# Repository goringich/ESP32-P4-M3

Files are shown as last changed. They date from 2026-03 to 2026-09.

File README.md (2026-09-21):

# ESP32-P4-M3 — spherical robot

This repository contains the ESP32-P4-M3 firmware/control stack and the current mechanical source for a pendulum-driven steerable spherical robot.

## Current engineering source of truth

The active mechanical project is:

`mechanical/spherical_robot/`

Key sources:

- `config/dimensions.json` — canonical mechanical dimensions, component envelopes and evidence status;
- `calculations.py` — deterministic sizing/load/traction screening;
- `blender/build_robot.py` + `blender/validate_robot.py` — exact assembly generation, topology and collision sweep;
- `simulation/` — reduced-order digital twin plus generated MuJoCo model contract;
- `DIGITAL_TWIN.md` — evidence ladder and commands;
- `NEEDS_MEASUREMENT.md` — physical measurements still required before final fits;
- `ASSEMBLY.md` and `PRINTING.md` — staged physical build path.

The historical `3D-model/fiish.*` files are not the current spherical-robot CAD authority.

## Verification

Dependency-free digital checks:

```bash
python -m unittest discover -s mechanical/spherical_robot/tests -p 'test_*.py'
python mechanical/spherical_robot/calculations.py --json
python mechanical/spherical_robot/simulation/run_sweep.py
python mechanical/spherical_robot/simulation/mujoco_model.py --output /tmp/spherical_robot.xml
```

Full geometry regeneration requires Blender:

```bash
blender --background --factory-startup --python mechanical/spherical_robot/blender/build_robot.py
```

MuJoCo, Project Chrono and FreeCAD/CalculiX are higher evidence layers. Their absence must be reported as pending/blocked; generated XML or Blender animation is not solver evidence and no simulation is physical validation.

## Firmware

ESP-IDF application code lives under `main/` and `components/`. The current repository includes MPU-9250, I2C, stepper/control, Wi-Fi/network and telemetry code.

Local/generated `sdkconfig` and `build/` remain ignored because they may contain machine-local configuration.

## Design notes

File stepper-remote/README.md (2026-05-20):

# Stepper Remote

This web stack is the operator UI for the ESP32-P4 gyroscope platform bench in this repo.

## What works

- Local web UI: served from the backend on `http://127.0.0.1:3001/`
- Serial workflow: browser -> local backend -> `/dev/ttyUSB0`
- Wi-Fi workflow: browser -> backend proxy -> ESP AP at `http://192.168.4.1`
- BLE status is exposed by firmware telemetry and shown in the UI

## One-command start

From the repo root:

```bash
./scripts/run_stepper_remote_web.sh
```

The script:

1. builds the frontend
2. builds the backend
3. starts the backend that serves the built frontend on `0.0.0.0:3001`

Then open:

- `http://127.0.0.1:3001/` for the main UI
- `http://127.0.0.1:3001/pad` for the simple pad view
- `http://<backend-host-ip>:3001/` from another device that can reach the backend host

## Important transport note

Opening the web UI locally and controlling the board over Wi-Fi are different things.

- The local UI can open as long as the backend is running.
- In `wifi` mode the browser talks only to the backend. The backend proxies requests to the ESP AP.
- Because of that, the browser device may stay on another Wi-Fi network if it can reach the backend host.
- But the backend host itself still must have a real route to the ESP AP: second adapter, dual-homed host, or router route.
- Wi-Fi transport from this PC to the ESP AP requires a real Wi-Fi adapter on the host.
- On this machine, recent checks showed `WIFI-HW missing`, so `http://192.168.4.1` is not reachable from this PC until Wi-Fi hardware is available.

Because of that:

- use `serial` mode from this workstation when working directly over USB
- use another phone/laptop with Wi-Fi if you want to drive the ESP AP over `wifi` mode
- or run the backend on a machine that can both reach `192.168.4.1` and expose `http://<backend-ip>:3001` to the browser device

## ESP AP credentials

- SSID prefix: `JC-ESP32P4M3`
- Password: `00000000`

## Backend ports

- backend API + static UI: `3001`
- frontend dev server, if you run it separately: Vite with `/api` proxy to `3001`

## Main API surfaces

- `GET /api/ports`
- `POST /api/connect`
- `POST /api/disconnect`
- `POST /api/command`
- `GET /api/telemetry`
- `GET /api/logs`
- `GET /api/logs/stream`
- `POST /api/transport`
- `POST /api/tooling/build`
- `POST /api/tooling/flash`

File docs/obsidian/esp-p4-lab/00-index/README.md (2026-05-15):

# ESP P4 Lab Documentation

Это корневая страница внутренней технической документации по проекту `p4_lab`.

Документация нужна не только чтобы "понять, где что лежит", а чтобы по ней можно было:

- быстро восстановить архитектуру проекта без чтения всего кода подряд;
- объяснить, как устроена прошивка, на защите или в курсовой;
- понять, какие подсистемы уже реализованы, а какие являются заготовками;
- брать готовые формулировки, схемы, цепочки вызовов и примеры кода.

## Что делает проект

Проект представляет собой прошивку для `ESP32-P4`, в которой объединены несколько учебно-практических задач:

- инициализация и диагностика `I2C`;
- обнаружение и опрос датчика семейства `MPU-9250`;
- управление шаговым двигателем через драйвер `L293D`;
- локальное управление через `UART`;
- сетевой доступ к состоянию и управлению через `Wi-Fi + HTTP + WebSocket`;
- периодическая выдача телеметрии в лог и в JSON.

По сути это лабораторный стенд, где одна прошивка показывает сразу несколько типовых подсистем встраиваемого ПО:

- low-level работа с шинами и GPIO;
- прикладной orchestration слой;
- сеть и API;
- телеметрия и диагностика;
- конфигурирование через `Kconfig`/`sdkconfig`.

## Краткая архитектура

Система разбита на понятные блоки:

- `main/main.c` — минимальная точка входа ESP-IDF;
- `components/app/src/app.c` — общий координатор жизненного цикла;
- `components/app/src/app_wifi.c` — запуск Wi‑Fi и хранение статуса;
- `components/app/src/app_net.c` — HTTP/WebSocket сервер и JSON API;
- `components/app/src/app_stepper.c` — логика шагового двигателя и команд;
- `components/app/src/app_mpu_pretty.c` — опрос MPU и форматирование телеметрии;
- `components/i2c_bus/src/i2c_bus.c` — универсальные операции I2C;
- `components/i2c_bus/src/i2c_bus_diag.c` — диагностика пар SDA/SCL;
- `components/mpu9250/src/mpu9250.c` — минимальный слой probe/WHO_AM_I.

Ключевая инженерная идея проекта: все внешние интерфейсы сводятся к небольшому набору публичных API, а `main` остается почти пустым.

## Что важно знать до чтения

1. Это не полный промышленный продукт, а учебно-исследовательская прошивка.
2. Некоторые функции есть как задел на будущее, но не везде уже встроены в активный runtime.
3. Документация ниже старается описывать именно **фактическое поведение текущего кода**, а не желаемое состояние.
4. Сеть сейчас строится вокруг SoftAP, а логика двигателя доступна и по UART, и через HTTP/WebSocket.

## Рекомендуемый маршрут чтения

Если нужно быстро войти в проект:

- [[00-index/Reading order]]
- [[02-architecture/System overview]]
- [[02-architecture/Boot and main loop]]
- [[02-architecture/Runtime data flow]]
- [[03-components/app component]]
- [[03-components/app_stepper]]
- [[03-components/app_net]]
- [[03-components/app_wifi]]
- [[03-components/i2c_bus]]
- [[03-components/mpu9250]]
- [[05-config/Configuration overview]]
- [[06-operations/Build and verification]]

Если нужен справочник:

- [[00-index/Function index]]
- [[00-index/Config index]]
- [[00-index/Source map]]

Если нужен материал именно под связный текст курсовой:

- [[08-course-paper/README]]
- [[08-course-paper/Technologies and stack]]
- [[08-course-paper/Engineering decisions]]
- [[08-course-paper/Current limitations]]
- [[08-course-paper/Future development]]

## Главные исходники

- `main/main.c`
- `components/app/src/app.c`
- `components/app/src/app_wifi.c`
- `components/app/src/app_net.c`
- `components/app/src/app_stepper.c`
- `components/app/src/app_mpu_pretty.c`
- `components/i2c_bus/src/i2c_bus.c`
- `components/i2c_bus/src/i2c_bus_diag.c`
- `components/mpu9250/src/mpu9250.c`
- `components/app/Kconfig`
- `components/i2c_bus/Kconfig`
- `sdkconfig`
- `sdkconfig.defaults`

## Что уже можно использовать в курсовой

Из этой базы уже можно брать:

- описание слоев архитектуры;
- последовательность загрузки и основного цикла;
- описание шины I2C и минимального драйверного слоя для MPU;
- описание сетевого API;
- описание схемы двойного управления двигателем;
- примеры структур состояния и JSON телеметрии;
- объяснение, как `Kconfig` влияет на состав функциональности.

Для более связного академического текста теперь также есть отдельный слой:

- стек технологий и платформы;
- инженерные решения по архитектуре;
- ограничения текущего прототипа;
- направления дальнейшего развития.

## Что сознательно не покрывается здесь

- `stepper-remote/backend`;
- `stepper-remote/frontend`;
- исходники внешнего SDK `esp-idf`;
- временные файлы сборки в `build/`.

Для них имеет смысл делать отдельный граф документации, чтобы не смешивать прикладную логику проекта с инфраструктурой SDK.

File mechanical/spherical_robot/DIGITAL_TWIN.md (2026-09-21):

# Spherical robot digital twin

## Goal

The digital twin binds the existing exact mechanical parameter/CAD pipeline to dynamics and later firmware/HIL evidence. It does **not** replace physical measurements or tests.

## Evidence ladder

1. `PARAMETER_CONTRACT_VALIDATED`
2. `ANALYTIC_BASELINE_PASS`
3. `CAD_COLLISION_SWEEP_PASS`
4. `PRIMARY_MULTIBODY_PASS` — MuJoCo execution
5. `INDEPENDENT_DYNAMICS_CROSSCHECK_PASS` — Project Chrono
6. `STRUCTURAL_ANALYSIS_PASS` — FreeCAD FEM/CalculiX when applicable
7. `CONTROLLER_IN_LOOP_PASS`
8. `HARDWARE_IN_LOOP_PASS`
9. `PHYSICAL_SUBASSEMBLY_PASS`
10. `PHYSICAL_SYSTEM_PASS`
11. `REPEATED_VALIDATION`

The repository deterministically produces levels 1–2, the existing Blender pipeline produces geometry/collision evidence for level 3, CI executes pinned MuJoCo 3.13.0 for level 4, and the dedicated heavyweight lane executes Project Chrono 10.0.0 as an independent level-5 cross-check. Levels 6+ remain separate evidence gates.

## Reduced-order model

`simulation/reduced_order.py` models one rolling plane using:

- sphere translation constrained to shell rotation;
- body translational + rotational inertia;
- absolute pendulum angle;
- equal/opposite motor torque between pendulum and body;
- gravity;
- damping/rolling-drag screening;
- motor torque-speed saturation;
- required floor contact force and normal-force estimate.

The model assumes no-slip rolling but computes a friction margin. Negative margin means that assumption is self-inconsistent and the scenario must be escalated to the contact solver; the code does not hide the violation by silently clamping it.

This model is deliberately not the authority for yaw/steering, contact compliance, shell deformation, backlash, battery sag, thermal behavior or real FDM material behavior.

## Reproducible baseline

```bash
python mechanical/spherical_robot/calculations.py --json
python -m unittest discover -s mechanical/spherical_robot/tests -p 'test_*.py'
python mechanical/spherical_robot/simulation/run_sweep.py
```

The sweep varies the existing ballast masses, arm radii and configured friction assumptions. Its output is provisional while the repository still contains `PLACEHOLDER`/`ASSUMED` inputs.

## MuJoCo

Generate an MJCF input artifact directly from canonical dimensions:

```bash
python mechanical/spherical_robot/simulation/mujoco_model.py \
  --output /tmp/spherical_robot.xml
```

XML generation alone remains `GENERATED_MODEL_NOT_EXECUTED`. The separate
`simulation/run_mujoco.py` path installs/executes pinned MuJoCo 3.13.0 in CI,
runs all 27 ballast/arm/friction combinations, verifies stable shell-floor
contact, bounded penetration, finite state, torque-speed limiting and a
positive/negative torque symmetry check, and records exact source hashes plus
solver/runtime versions. Only that executed path may emit
`PRIMARY_MULTIBODY_PASS`.

Run it locally after installing the pinned dependency:

```bash
python -m pip install -r mechanical/spherical_robot/simulation/requirements-simulation.txt
MUJOCO_GL=egl python mechanical/spherical_robot/simulation/run_mujoco.py
```

A MuJoCo pass still leaves the design verdict `PROVISIONAL` while canonical
inputs remain `PLACEHOLDER`/`ASSUMED`; it does not imply physical acceptance.

The MuJoCo model contains:

- free spherical body/contact shell;
- internal steering-yaw joint;
- pendulum hinge and ballast;
- bounded motor actuators;
- floor contact/friction;
- IMU-like accelerometer/gyro plus joint sensors.

## Independent cross-check and FEA

Release-critical dynamics must be cross-checked with Project Chrono (or another independently implemented multibody method). Load-bearing geometry requiring more than analytical screening must use FreeCAD FEM/CalculiX or a justified equivalent, with loads bound to the dynamics evidence.

## Controller and HIL

The next software layer should expose a stable semantic interface:

- IMU acceleration/angular velocity;
- pendulum angle/speed;
- steering angle;
- requested pendulum torque/speed;
- requested steering actuation;
- health/saturation/watchdog state.

The real control algorithm should first run controller-in-loop against the simulated plant. After that, the ESP32-P4-M3 can run HIL against the same interface. HIL still does not prove real floor friction, printed fit, RF, battery, thermal or wear behavior.

## Physical calibration loop

After the first safe subassembly/rolling tests, feed measured values back into the model:

- actual total/component masses and COM;
- actual motor torque-speed-current behavior;
- backlash/deadband;
- floor/grip friction;
- rolling resistance;
- IMU bias/noise/latency;
- battery sag;
- real pendulum and steering limits.

Every calibration update invalidates dependent simulation evidence until rerun.

## Project Chrono independent cross-check

The heavyweight CI lane uses official PyChrono 10.0.0 through its recommended
Conda distribution. `simulation/run_chrono.py` rebuilds an independent
Y-up/NSC/Bullet rigid-body model rather than reusing MuJoCo internals. It runs
the same 27 ballast/arm/friction scenarios and a ±torque symmetry pair.

`simulation/compare_multibody.py` then binds both solver reports to the same
canonical source hashes and checks scenario identity, rolling direction
agreement, bounded median response magnitude and independent symmetry. This may
emit `INDEPENDENT_DYNAMICS_CROSSCHECK_PASS`; it still cannot set
`physical_accepted=true`.

## Structural FEA screening

`fea/run_structural_fea.py` runs the tracked `PENDULUM_ARM.stl` through
Gmsh and CalculiX. Until coupon-backed anisotropic FDM properties and the final
slicer topology are bound, a green solve is only
`STRUCTURAL_FEA_SCREENING_PASS`, not `STRUCTURAL_ANALYSIS_PASS` and never
physical acceptance. See `STRUCTURAL_FEA.md`.

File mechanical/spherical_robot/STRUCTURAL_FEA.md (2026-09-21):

# Structural FEA screening

This lane adds a real finite-element solver check for the most load-sensitive
printed pendulum member: `PENDULUM_ARM.stl`.

## Evidence level

A successful run emits:

`STRUCTURAL_FEA_SCREENING_PASS`

It deliberately does **not** emit `STRUCTURAL_ANALYSIS_PASS`.

The tracked STL is meshed and solved, but printed PETG is currently represented
as an assumed isotropic solid. The real part uses walls + infill and has
direction-dependent FDM properties. Coupon-backed properties and a release load
case are required before structural release authority.

## Pipeline

```
tracked PENDULUM_ARM.stl
  -> Gmsh 4.15.2 surface classification
  -> first-order tetrahedral volume mesh
  -> CalculiX C3D4 static solve
  -> integration-point stress
  -> nodal displacement
  -> fail-closed screening report
```

The solver uses N/mm/MPa units.

## Load case

The screening load uses the maximum configured ballast mass plus the current
assumed pendulum-extra mass, multiplies it by a 5 g shock factor, and assigns
half to one arm. The root end is fixed and the force is distributed over the
opposite end in the weakest bending direction.

This is intentionally conservative, but it is still an abstraction of the real
two-bolt hub and ballast-saddle interfaces.

## Local run

Ubuntu/Debian dependencies:

```bash
sudo apt-get install calculix-ccx libglu1-mesa
python -m pip install -r mechanical/spherical_robot/fea/requirements-fea.txt
python mechanical/spherical_robot/fea/run_structural_fea.py
```

The report always retains `physical_accepted=false`.

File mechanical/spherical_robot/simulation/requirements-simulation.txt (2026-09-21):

# Primary multibody solver used by the spherical-robot exact-head CI.
# Pin the engine version so evidence can be tied to one deterministic solver release.
mujoco==3.13.0

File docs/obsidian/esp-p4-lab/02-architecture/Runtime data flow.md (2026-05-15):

# Runtime data flow

Этот раздел описывает, как реальные данные и команды проходят через систему во время выполнения.

## 1. Поток запуска системы

После загрузки микроконтроллера выполняется следующий сценарий:

1. `app_main()` пишет лог `boot`.
2. `app_main()` вызывает `app_init()`.
3. `app_init()` по очереди поднимает:
	- I2C;
	- I2C scan;
	- MPU WHO_AM_I check;
	- Wi‑Fi smoke run, если включен;
	- stepper subsystem, если включен режим `L293D_TEST`;
	- HTTP/WebSocket API, если включена сеть и Wi‑Fi успешно поднят.
4. Затем `app_main()` переходит в бесконечный цикл `app_tick()`.

Идея в том, что тяжелая инициализация выполняется один раз, а дальше система живет за счет коротких периодических вызовов.

## 2. Поток управления шаговым двигателем

### Через UART

Путь данных:

`UART0` → `app_stepper_handle_uart()` → `app_stepper_handle_command()` → изменение `s_stepper`

Подробно:

- `app_stepper_tick()` опрашивает UART, если `uart_ready == true`;
- считанные байты перебираются по одному;
- каждый символ интерпретируется как команда (`f`, `r`, `s`, `w`, `+`, `-`, и т.д.);
- обработчик обновляет внутренний state machine двигателя.

### Через HTTP

Путь данных:

HTTP `POST /api/command` → `app_net_command_handler()` → `app_net_extract_command()` → `app_stepper_command_char()` → `app_stepper_handle_command()`

Сетевой слой не знает, как именно устроены фазы двигателя. Он только выделяет символ команды и передает его вниз.

### Через WebSocket

Путь данных:

WebSocket text frame → `app_net_ws_handler()` → `app_net_extract_command()` → `app_stepper_command_char()` → `app_stepper_handle_command()`

Это тот же самый исполнительный путь, что и в HTTP. Разница только в транспорте.

## 3. Поток вычисления шага двигателя

Даже если новых команд нет, `app_stepper_tick()` продолжает обслуживать state machine.

### В режиме `sweep`

Алгоритм такой:

- двигатель идет вперед до `APP_STEPPER_SWEEP_STEPS`;
- затем делается пауза `APP_STEPPER_EDGE_PAUSE_MS`;
- после этого двигатель идет назад;
- потом снова пауза;
- цикл повторяется.

Внутри этого механизма используются:

- `s_stepper.mode`;
- `s_stepper.sweep_state`;
- `s_stepper.last_step_ms`;
- `s_stepper.pause_started_ms`;
- `s_stepper.moved_steps_in_leg`.

Физическое движение реализуется через последовательное включение фаз из массива `s_phases`.

## 4. Поток получения телеметрии MPU

Путь данных:

`app_tick()` → `app_mpu_pretty_log_line()` → `app_mpu_pretty_init()` → `i2c_bus_read()` → вычисление физических значений → лог + status + telemetry line

Что происходит по шагам:

1. Раз в секунду `app.c` решает, что пора вывести телеметрию.
2. Если MPU еще не инициализирован, вызывается `app_mpu_pretty_init()`.
3. Через `mpu9250_probe_and_read_whoami()` определяется адрес и код `WHO_AM_I`.
4. Через `i2c_bus_read()` читаются `GYRO_CONFIG`, `ACCEL_CONFIG`, а затем блок данных с `ACCEL_XOUT_H`.
5. Сырые 16-битные значения переводятся в:
	- ускорения в `g`;
	- угловые скорости в `dps`;
	- температуру в `°C`.
6. Результат одновременно:
	- печатается в красивом текстовом виде;
	- сохраняется в `app_mpu_status_t`;
	- публикуется как строка `@telemetry {...}`.

## 5. Поток системной телеметрии

Раз в секунду `app.c` также обновляет общий статус системы:

- `ready`;
- `uptime_ms`;
- `tick`;
- `tick_delay_ms`;
- `firmware`;
- `app_mode`;
- `last_error`.

Затем печатается отдельная telemetry-строка вида:

```text
@telemetry {"kind":"system", ...}
```

Это важно, потому что системная телеметрия и сенсорная телеметрия формируются независимо, но на одинаковой идее — выдавать машинно-читаемый JSON в лог.

## 6. Поток сборки JSON для сети

Путь данных:

`app_net_build_json()` ← `app_stepper_get_snapshot()`
`app_net_build_json()` ← `app_wifi_get_status()`
`app_net_build_json()` ← `app_get_system_status()`
`app_net_build_json()` ← `app_mpu_get_status()`
`app_net_build_json()` ← `app_get_i2c_status()`

Это один из самых важных архитектурных моментов.

`app_net` ничего не "вытаскивает" из чужих внутренних static-переменных. Он получает готовые слепки состояния через публичный API. В результате:

- связи между компонентами слабее;
- сетевой слой проще менять;
- состояние удобно сериализовать;
- документация на API становится понятнее.

## 7. Поток отдачи данных наружу

### HTTP pull-модель

- `GET /api/telemetry` → возвращает полный JSON состояния;
- `GET /api/wifi` → возвращает Wi‑Fi статус.

### WebSocket push-модель

Раз в секунду `app_net_tick()`:

- получает список клиентских сокетов;
- проверяет, какие из них являются WebSocket-клиентами;
- собирает единый JSON;
- ставит асинхронную отправку через `httpd_queue_work()`.

Эта схема удобна для web-dashboard: клиент не обязан постоянно опрашивать REST endpoint.

## 8. Поток ошибок и деградации

В проекте предусмотрена мягкая деградация, а не только "успех или аварийный стоп".

Примеры:

- если I2C init не удался, `app_init()` пишет ошибку и прекращает дальнейшую инициализацию;
- если MPU не найден, выполняется дополнительная диагностика пар GPIO;
- если Wi‑Fi поднять не удалось, сетевой API не стартует;
- если UART driver не поднялся, логика двигателя все равно остается доступной внутри прошивки и через сетевой слой;
- ошибки MPU записываются в `last_error` и публикуются в телеметрии.

## 9. Главная архитектурная развязка

В текущем проекте особенно важно следующее разделение:

- `app_net` не знает внутренних enum и state machine двигателя;
- `app_net` не трогает GPIO напрямую;
- `app_wifi` не знает про шаговый двигатель;
- `app_stepper` не знает ничего про HTTP server и WebSocket;
- `app_mpu_pretty` не знает ничего про HTTP, но публикует состояние, которое сеть потом читает;
- `app.c` выступает единственным orchestration-слоем.

Именно это делает проект пригодным для масштабирования и хорошим примером для пояснения в курсовой работе.

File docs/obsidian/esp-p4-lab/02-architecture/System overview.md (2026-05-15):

# System overview

## Назначение системы

Прошивка `p4_lab` — это учебно-прикладная embedded-система для `ESP32-P4`, в которой одновременно демонстрируются несколько важных подсистем:

- циклическая архитектура приложения поверх `FreeRTOS`;
- конфигурируемая работа с `I2C`;
- обнаружение и опрос `MPU-9250`;
- управление шаговым двигателем через `L293D`;
- локальное управление через `UART`;
- удаленное управление и чтение телеметрии через `Wi‑Fi`, `HTTP` и `WebSocket`.

Проект хорошо подходит как основа для курсовой, потому что в нем есть и работа с железом, и сетевой API, и конфигурируемая архитектура, и телеметрия.

## Слои архитектуры

Прошивка разделена на несколько уровней ответственности.

### 1. Входной слой

- `main/main.c`

Этот слой намеренно минимален. Он не знает деталей ни про Wi‑Fi, ни про I2C, ни про шаговый двигатель. Его задача — запустить прикладной слой и поддерживать бесконечный цикл:

- `app_init()` один раз;
- `app_tick()` в цикле;
- задержка между итерациями через `app_tick_delay_ms()`.

### 2. Прикладной координационный слой

- `components/app/src/app.c`

Здесь собрана общая логика жизненного цикла. Файл:

- инициализирует подсистемы в нужном порядке;
- хранит системный статус;
- хранит сводный статус I2C/MPU обнаружения;
- решает, запускать ли сетевой API;
- раз в секунду порождает телеметрию.

Это фактический центр композиции всего проекта.

### 3. Инфраструктурные и прикладные модули

- `app_wifi` — сеть;
- `app_net` — API и транспорт JSON/WS;
- `app_stepper` — исполнительный механизм;
- `app_mpu_pretty` — сенсорная телеметрия;
- `i2c_bus` — базовая шина;
- `mpu9250` — минимальный sensor helper.

## Схема связей между модулями

В текущей реализации зависимости выглядят так:

- `main` зависит только от `app`;
- `app` зависит от `app_wifi`, `app_net`, `app_stepper`, `app_mpu_pretty`, `i2c_bus`, `mpu9250`;
- `app_net` зависит от публичных snapshot/status API других подсистем;
- `app_mpu_pretty` зависит от `i2c_bus` и `mpu9250`;
- `mpu9250` зависит от `i2c_bus`.

Важно, что сетевой слой **не управляет GPIO напрямую** и **не работает с внутренними enum stepper напрямую**. Он общается с моторной подсистемой через маленький публичный API:

- `app_stepper_command_char()`;
- `app_stepper_get_snapshot()`.

Это хорошее архитектурное решение: транспорт и исполнительная логика разделены.

## Ключевая идея проекта

Главная идея системы — объединить несколько каналов управления и наблюдения, но не перемешивать их реализацию.

### Единый обработчик команд

Локальный `UART` и сетевые команды работают через один и тот же обработчик моторных команд. Это дает:

- одинаковое поведение независимо от канала управления;
- меньше дублирования логики;
- более простую отладку;
- единый формат состояния двигателя.

### Телеметрия как отдельный слой

Проект не ограничивается "сделать действие". Он еще и показывает состояние:

- через текстовый лог в UART/monitor;
- через JSON по `HTTP`;
- через push-модель по `WebSocket`;
- через отдельные `@telemetry` строки, пригодные для дальнейшего парсинга.

Это особенно полезно для стенда, лабораторной работы и курсовой, потому что можно показать не только код, но и наблюдаемое поведение системы.

## Что именно уже реализовано в текущем коде

### Реализовано точно

- инициализация I2C-шины;
- быстрый scan MPU-адресов `0x68` и `0x69`;
- fallback-диагностика альтернативных пар SDA/SCL при неудаче;
- чтение `WHO_AM_I`;
- чтение сырых значений accel/gyro/temp;
- вычисление физических величин;
- автоматический запуск stepper в режиме `sweep`;
- прием команд через `UART0`;
- REST endpoint для телеметрии;
- REST endpoint для Wi‑Fi статуса;
- REST endpoint для команд stepper;
- WebSocket endpoint;
- периодическая рассылка JSON по WebSocket.

### Есть в коде, но не полностью задействовано

- функция `app_wifi_log_scan_results()` существует, но в текущем коде не вызывается;
- функция построения SSID умеет добавлять MAC-суффикс, но сейчас вызывается с `NULL`, поэтому реально используется только `CONFIG_APP_WIFI_AP_SSID_PREFIX` без суффикса;
- выбор режима приложения через `choice APP_MODE` существует в `Kconfig`, но `app.c` фактически использует `CONFIG_APP_MODE_L293D_TEST` и логику MPU параллельно, то есть проект уже не является строго "однорежимным" в архитектурном смысле.

Эти детали важно зафиксировать в документации, потому что для курсовой полезно показывать не только сильные стороны, но и реальные инженерные компромиссы.

## Сильные стороны архитектуры

- маленький и чистый `main`;
- четкое разделение по компонентам;
- конфигурируемость через `Kconfig`;
- единая точка orchestration в `app.c`;
- общий обработчик команд stepper для разных транспортов;
- отдельный status/snapshot API для интеграции с сетью;
- упор на диагностику и наблюдаемость.

## Ограничения текущего варианта

- нет отдельной RTOS-задачи на каждую подсистему — используется один кооперативный tick-loop;
- JSON собирается вручную через `snprintf`, без полноценной JSON-библиотеки;
- `i2c_bus_read()`/`write()` каждый раз создают и удаляют device handle, что просто, но не оптимально для высокой частоты опроса;
- Web UI живет вне этой части документации;
- проект больше ориентирован на лабораторный стенд, чем на production deployment.

## Почему такая архитектура удобна для курсовой

Она дает материал сразу по нескольким темам:

- архитектура embedded-приложения;
- модульность и слои ответственности;
- работа с периферией и датчиками;
- управление исполнительным устройством;
- взаимодействие микроконтроллера и сети;
- телеметрия и диагностика;
- конфигурирование и сборка в ESP-IDF.

См. также:

- [[02-architecture/Boot and main loop]]
- [[02-architecture/Runtime data flow]]
- [[02-architecture/UART and network dual control]]
- [[02-architecture/WiFi HTTP WebSocket architecture]]

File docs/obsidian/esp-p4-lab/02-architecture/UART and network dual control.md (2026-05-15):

# UART and network dual control

## Архитектурная задача

Одна из главных задач проекта — расширить управление шаговым двигателем через сеть, но не потерять уже существующее UART-управление.

Это важный инженерный сценарий: часто в embedded-проектах новый интерфейс нужно добавить поверх старого, не ломая уже работающий способ диагностики и ручного контроля.

## Принцип решения

В проекте выбрано очень удачное решение:

- UART остается внутри `app_stepper.c`;
- сетевой слой не дублирует motor logic;
- наружу добавляется компактный публичный вызов `app_stepper_command_char(char cmd)`;
- и UART, и сеть в итоге сходятся в одном внутреннем обработчике `app_stepper_handle_command(uint8_t cmd)`.

Это означает, что логика интерпретации команд реализована **один раз**.

## Потоки управления

### Путь UART

```text
UART0 -> app_stepper_handle_uart -> app_stepper_handle_command
```

### Путь HTTP

```text
POST /api/command -> app_net_command_handler -> app_stepper_command_char -> app_stepper_handle_command
```

### Путь WebSocket

```text
/ws text frame -> app_net_ws_handler -> app_stepper_command_char -> app_stepper_handle_command
```

Таким образом, три разных транспортных входа приводят к одной и той же исполнительной логике.

## Почему это важно

Такой подход дает сразу несколько преимуществ:

- нет копипасты командной логики;
- поведение одинаково независимо от источника команды;
- проще тестировать и отлаживать;
- при добавлении новой команды ее нужно реализовать в одном месте;
- старый UART-канал продолжает работать как fallback и инструмент отладки.

## Набор команд остается единым

Сохраняется совместимость команд:

- `f`, `r`, `s`, `w`
- `1`, `2`
- `a`, `b`, `c`, `d`
- `+`, `-`
- `z`

То есть оператор, который привык управлять двигателем через UART-символы, фактически может использовать тот же протокол через HTTP/WebSocket.

## Почему это хорошее решение для курсовой

На этом месте можно показать важный инженерный принцип:

> новые интерфейсы не должны дублировать бизнес-логику, они должны переиспользовать существующий domain layer.

В терминах архитектуры проекта:

- `UART` и `HTTP/WebSocket` — это transport layer;
- `app_stepper_handle_command()` — это command execution layer.

## Ограничения текущей схемы

- команды односимвольные, поэтому протокол простой, но не слишком расширяемый;
- нет механизма очередей команд или приоритетов между каналами;
- нет явной арбитрации, если UART и сеть начнут слать команды очень часто одновременно;
- вся обработка выполняется внутри общего tick-loop.

Однако для лабораторного стенда такая схема оптимальна: она проста, надежна и очень понятна при объяснении.

## Практический смысл

В реальной демонстрации это дает очень удобный набор возможностей:

- можно управлять мотором с serial monitor;
- можно управлять через `curl`;
- можно подключить web-клиент;
- при проблемах с сетью UART остается резервным способом контроля.

Именно это делает проект не просто набором отдельных функций, а удобной экспериментальной платформой.

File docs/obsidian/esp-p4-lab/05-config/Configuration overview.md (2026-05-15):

# Configuration overview

## Зачем здесь нужен отдельный раздел про конфигурацию

В ESP-IDF проекте значительная часть поведения определяется не только кодом, но и конфигурацией. В `p4_lab` это особенно заметно: через конфиг управляются:

- состав активных подсистем;
- GPIO для I2C и stepper;
- частота I2C;
- параметры Wi‑Fi;
- включение сетевого API;
- параметры UART и LED для stepper.

То есть для полного понимания проекта нужно читать и код, и конфигурацию вместе.

## Главные файлы конфигурации

- `components/app/Kconfig`
- `components/i2c_bus/Kconfig`
- `sdkconfig`
- `sdkconfig.defaults`
- `CMakeLists.txt`

## Роль каждого файла

### `components/app/Kconfig`

Описывает прикладные настройки проекта:

- режим приложения;
- включение tick-логирования;
- Wi‑Fi smoke run;
- параметры SoftAP;
- включение попытки STA-подключения;
- включение HTTP/WebSocket API;
- GPIO и timing для L293D;
- настройки UART stepper;
- optional LED activity.

### `components/i2c_bus/Kconfig`

Описывает инфраструктурные параметры I2C:

- `CONFIG_I2C_BUS_SDA_GPIO`;
- `CONFIG_I2C_BUS_SCL_GPIO`;
- `CONFIG_I2C_BUS_FREQ_HZ`.

### `sdkconfig`

Это итоговая конфигурация текущей сборки. Именно она реально влияет на компиляцию и работу прошивки в данной рабочей копии.

### `sdkconfig.defaults`

Хранит базовые значения по умолчанию, которые особенно важны при создании новой конфигурации или переносе проекта на другое рабочее место.

## Важные настройки `components/app/Kconfig`

### Выбор режима приложения

В `Kconfig` есть выбор:

- `APP_MODE_MPU9250`
- `APP_MODE_L293D_TEST`

Но важно понимать практический нюанс: текущий код уже использует и моторную, и MPU-логику одновременно. Поэтому формально `choice` есть, но архитектурно проект уже вышел за рамки строго одного режима.

### Логирование

- `CONFIG_APP_TICK_LOG`

Когда включено, `app.c` раз в секунду генерирует системную и MPU-телеметрию.

### Wi‑Fi

- `CONFIG_APP_WIFI_SMOKE`
- `CONFIG_APP_WIFI_AP_SSID_PREFIX`
- `CONFIG_APP_WIFI_AP_PASSWORD`
- `CONFIG_APP_WIFI_AP_CHANNEL`
- `CONFIG_APP_WIFI_SCAN_MAX_AP`
- `CONFIG_APP_WIFI_CONNECT`
- `CONFIG_APP_WIFI_SSID`
- `CONFIG_APP_WIFI_PASSWORD`
- `CONFIG_APP_NET_ENABLE`

Из этих параметров складывается сетевое поведение прошивки.

### Stepper / L293D

- `CONFIG_APP_L293D_IN1_GPIO`
- `CONFIG_APP_L293D_IN2_GPIO`
- `CONFIG_APP_L293D_IN3_GPIO`
- `CONFIG_APP_L293D_IN4_GPIO`
- `CONFIG_APP_L293D_STEP_DELAY_MS`
- `CONFIG_APP_STEPPER_UART_BAUD_RATE`
- `CONFIG_APP_STEPPER_LED_ENABLE`
- `CONFIG_APP_STEPPER_LED_GPIO`

Это критическая часть для аппаратной привязки проекта к конкретному стенду.

## Текущие значимые значения конфигурации

По состоянию текущего проекта особенно важны следующие опции:

- `CONFIG_IDF_TARGET="esp32p4"`
- `CONFIG_HTTPD_WS_SUPPORT=y`
- `CONFIG_ESP_WIFI_REMOTE_ENABLED=y`
- `CONFIG_ESP_WIFI_REMOTE_LIBRARY_HOSTED=y`
- `CONFIG_ESP_HOSTED_ENABLED=y`
- `CONFIG_ESP_HOSTED_CP_TARGET_ESP32C6=y`
- `CONFIG_ESP_HOSTED_P4_DEV_BOARD_FUNC_BOARD=y`
- `CONFIG_ESP_HOSTED_SDIO_HOST_INTERFACE=y`
- `CONFIG_APP_MODE_L293D_TEST=y`
- `CONFIG_APP_WIFI_SMOKE=y`
- `CONFIG_APP_NET_ENABLE=y`
- `CONFIG_APP_WIFI_AP_SSID_PREFIX="JC-ESP32P4M3"`
- `CONFIG_APP_WIFI_AP_PASSWORD="esp32p4m3"`
- `CONFIG_APP_WIFI_AP_CHANNEL=1`
- `# CONFIG_APP_WIFI_CONNECT is not set`

## Что это означает в runtime

Из этих значений следует:

- проект собирается под `ESP32-P4`;
- WebSocket support включен;
- сеть построена через hosted Wi‑Fi стек, связанный с `ESP32-C6`;
- активирован режим stepper-стенда;
- при старте поднимается Wi‑Fi smoke/bringup;
- доступен HTTP/WebSocket API;
- устройство поднимает собственную точку доступа;
- попытка подключения к внешнему роутеру сейчас по умолчанию не выполняется.

## Почему `Kconfig` важен для архитектуры

Через конфиг в проекте решаются сразу две задачи:

1. аппаратная параметризация;
2. функциональная композиция прошивки.

Это делает один и тот же код переиспользуемым в разных вариантах стенда без ручного редактирования исходников.

## Что полезно показать в курсовой

В курсовой по этому разделу можно явно подчеркнуть:

- почему в embedded-проекте конфигурация равноправна коду;
- как `Kconfig` помогает переносить проект между стендами;
- как compile-time флаги влияют на состав подсистем;
- как конфиг определяет сетевой и аппаратный профиль устройства.

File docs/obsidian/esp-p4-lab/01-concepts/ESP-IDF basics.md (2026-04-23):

# ESP-IDF basics

ESP-IDF - это официальный фреймворк Espressif для прошивок ESP32-семейства.

В этом проекте он дает:

- точку входа `app_main()`;
- компоненты через `idf_component_register`;
- конфигурацию через `Kconfig`, `menuconfig`, `sdkconfig`;
- драйверы GPIO, UART, I2C, Wi-Fi;
- HTTP server;
- FreeRTOS scheduler;
- систему логирования `ESP_LOGI`, `ESP_LOGW`, `ESP_LOGE`;
- тип ошибок `esp_err_t`.

Проект не является обычной Linux-программой. После прошивки код работает на микроконтроллере. Поэтому `main/main.c` не завершает программу, а входит в бесконечный цикл:

```c
while (1) {
  app_tick();
  vTaskDelay(pdMS_TO_TICKS(app_tick_delay_ms()));
}
```

См. [[02-architecture/Boot and main loop]].

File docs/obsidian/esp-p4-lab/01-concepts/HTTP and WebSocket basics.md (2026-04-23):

# HTTP and WebSocket basics

Проект использует две сетевые модели:

- HTTP request/response для точечных запросов;
- WebSocket для постоянного соединения и периодической телеметрии.

HTTP endpoints:

- `GET /api/telemetry`: возвращает общий JSON с состоянием stepper и Wi-Fi.
- `GET /api/wifi`: возвращает только Wi-Fi status.
- `POST /api/command`: принимает команду для stepper.
- `OPTIONS /*`: отвечает на CORS preflight.

WebSocket endpoint:

- `GET /ws`: WebSocket handshake;
- входящее текстовое сообщение может содержать команду;
- раз в секунду `app_net_tick()` рассылает telemetry JSON всем WebSocket-клиентам.

См. [[03-components/app_net]], [[04-functions/app_net_ws_handler]], [[04-functions/app_net_tick]].

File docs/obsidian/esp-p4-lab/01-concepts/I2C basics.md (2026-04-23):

# I2C basics

I2C - это двухпроводная шина:

- `SDA`: линия данных;
- `SCL`: линия тактового сигнала.

В проекте I2C используется для MPU9250 или совместимого IMU-сенсора.

Важные детали:

- адрес MPU обычно `0x68` или `0x69`;
- перед чтением регистра master отправляет адрес регистра;
- затем читает нужное количество байт;
- линии должны быть подтянуты вверх;
- если `SDA` или `SCL` в idle состоянии равны `0`, это часто признак проблемы проводки, питания или подтяжек.

Код I2C вынесен в `components/i2c_bus`.

См. [[03-components/i2c_bus]], [[04-functions/i2c_bus_init]], [[04-functions/i2c_bus_scan]].

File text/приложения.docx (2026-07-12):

ФЕДЕРАЛЬНОЕ ГОСУДАРСТВЕННОЕ АВТОНОМНОЕ ОБРАЗОВАТЕЛЬНОЕ УЧРЕЖДЕНИЕ

ВЫСШЕГО ОБРАЗОВАНИЯ

«НАЦИОНАЛЬНЫЙ ИССЛЕДОВАТЕЛЬСКИЙ УНИВЕРСИТЕТ

«ВЫСШАЯ ШКОЛА ЭКОНОМИКИ»

Факультет информатики, математики и компьютерных наук

Образовательная программа «Компьютерные науки и технологии»

Ким Игорь Геннадьевич, группа 23КНТ-6

ПРИЛОЖЕНИЯ К КУРСОВОЙ РАБОТЕ

«Разработка системы беспроводного управления гиростабилизируемой платформой»

Научный руководитель:

Морозов Никита Сергеевич, доцент кафедры радиотехники РФФ ННГУ

Нижний Новгород, 2026

# Оглавление

Приложение А. Аппаратная схема подключения 3

Приложение Б. Структура телеметрии, API и команд 5

Приложение В. Алгоритмическая часть и параметры обработки IMU 7

Приложение Г. Программа испытаний и контрольные результаты 9

Приложение Д. Механическая часть и 3D-печатный корпус 10

Приложение Е. Служебные команды прошивки и запуска 11

Приложение Ж. Иллюстративные материалы 12

Приложение З. Ссылка на репозиторий 12

# Приложение А. Аппаратная схема подключения

В приложении приведены технические сведения, вынесенные из основной части отчета для разгрузки текста. Эти данные используются для воспроизведения стенда, проверки проводных соединений и объяснения работы прототипа на защите.

Вывод модуля GY-9250 / MPU-9250 | Подключение | Назначение
VCC | 3.3 В | Питание IMU
GND | GND | Общая земля системы
SDA/SDI | GPIO1 | Линия данных I2C
SCL/SCLK | GPIO2 | Линия тактирования I2C
NCS | 3.3 В | Выбор I2C-режима модуля
AD0/SDO | GND | Адрес I2C 0x68
INT | Не подключен | В базовом опросе не используется
FSYNC | Не подключен | В базовом опросе не используется

Сигнал L293D | GPIO / линия | Назначение
IN1 | GPIO3 | Управление каналом A, направление +
IN2 | GPIO4 | Управление каналом A, направление -
IN3 | GPIO5 | Управление каналом B, направление +
IN4 | GPIO20 | Управление каналом B, направление -
ENA | VCC | Постоянное включение канала A
ENB | VCC | Постоянное включение канала B
VM | 5 В / Vin | Питание моторов от отдельного источника
GND | GND | Общая земля ESP, драйвера и моторов
OUT1/OUT2 | Motor A | Первый TT DC motor
OUT3/OUT4 | Motor B | Второй TT DC motor

Для корректной работы важно, чтобы логическая и силовая части имели общий GND. Без общего отсчета входы драйвера могут интерпретировать уровни GPIO некорректно. Силовое питание моторов целесообразно прокладывать отдельно от линий I2C, так как двигатели создают помехи и кратковременные просадки напряжения.

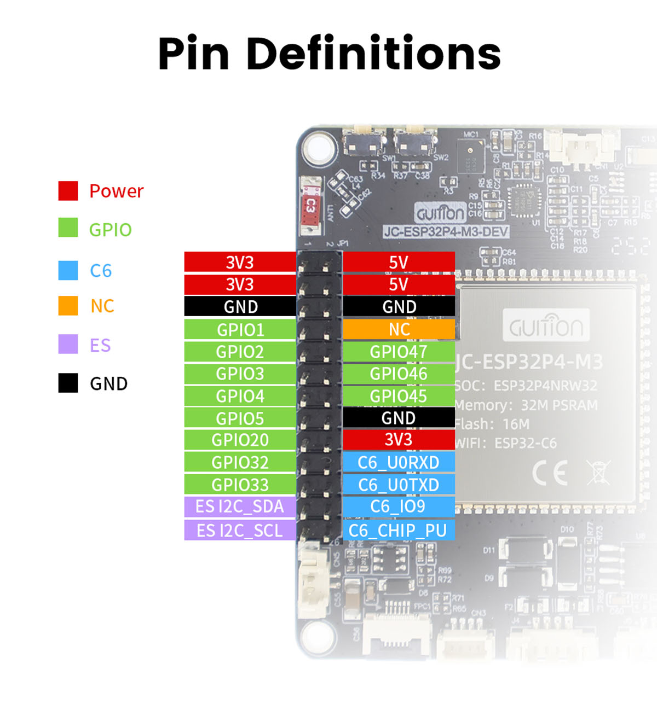
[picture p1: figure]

Рисунок А.1 - Рабочая карта выводов JC-ESP32P4-M3

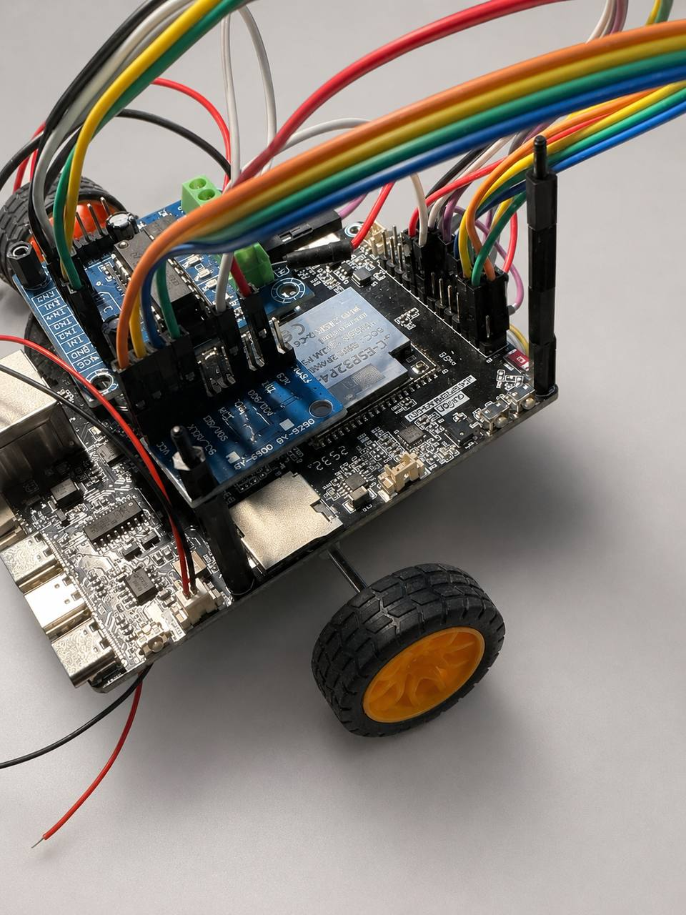
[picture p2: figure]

Рисунок А.2 - Открытый стенд для проверки платы, драйвера и колесного узла

# Приложение Б. Структура телеметрии, API и команд

Телеметрия организована как структурированное состояние устройства. Она нужна не только для отображения чисел в интерфейсе, но и для инженерной диагностики: по ней видно, отвечает ли IMU, доступна ли сеть, в каком режиме находится привод и какие события происходили в системе.

Раздел телеметрии | Назначение
system | Общее состояние устройства, режим работы, счетчики, диагностические признаки.
mpu | Адрес датчика, WHO_AM_I, модель, сырые и преобразованные значения IMU.
i2c | Состояние шины, найденные адреса, диагностические сообщения.
wifi | Режим беспроводного интерфейса, доступность сети, IP-адрес.
actuator / stepper | Состояние исполнительного механизма, текущая команда, скорость и режим.

Endpoint | Назначение
GET /api/telemetry | Получение текущего состояния устройства, IMU, I2C, Wi-Fi и привода.
GET /api/wifi | Получение состояния беспроводного интерфейса.
POST /api/command | Передача управляющей команды на устройство.
OPTIONS /* | Поддержка CORS/preflight-запросов для frontend-приложения.
GET /ws | WebSocket-поток событий и телеметрии.

Команда | Назначение | Использование при испытаниях
Stop | Остановить привод | Безопасное состояние перед началом и после окончания теста.
Forward | Движение вперед | Проверка направления вращения.
Reverse | Движение назад | Проверка обратного направления.
Step + | Пошаговое смещение вперед | Дискретная проверка реакции механики.
Step - | Пошаговое смещение назад | Проверка обратного дискретного шага.
Faster | Увеличить скорость | Проверка изменения параметра движения.
Slower | Уменьшить скорость | Проверка нижнего предела скорости.
Status | Запросить состояние | Проверка обратной связи от устройства.
Release coils | Отключить удержание каналов | Безопасная разгрузка исполнительного узла.

Frontend-пульт содержит вкладки Overview, Control и Console, а также отдельный экран Wi-Fi motor pad. Фактически доступные элементы управления: Stop, Sweep, Forward, Reverse, Step +, Step -, Faster, Slower, A/B/C/D, Release coils, Request status и четырехкнопочный режим UP/LEFT/RIGHT/DOWN.

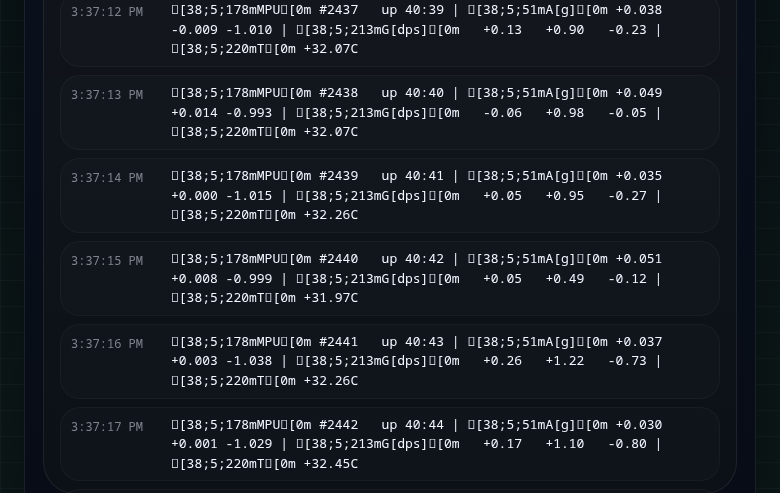
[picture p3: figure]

Рисунок Б.1 - Фрагмент отображения телеметрии IMU в интерфейсе

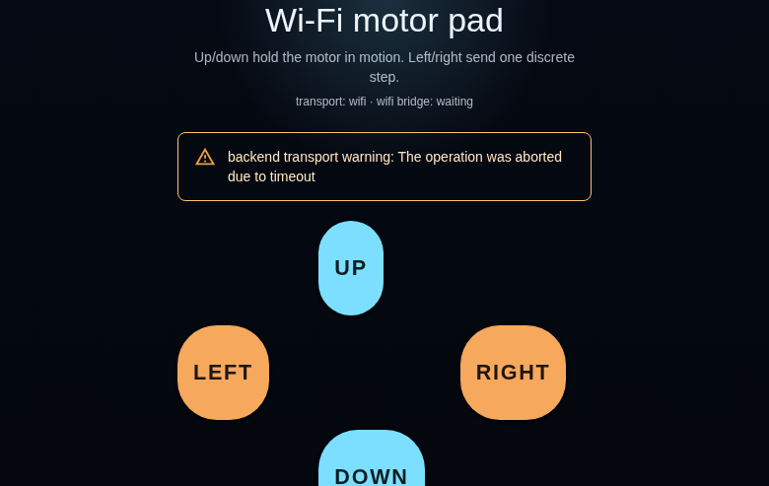
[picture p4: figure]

Рисунок Б.2 - Экран Wi-Fi motor pad для ручного управления

# Приложение В. Алгоритмическая часть и параметры обработки IMU

Алгоритмическая часть описывает, как данные IMU могут использоваться для оценки наклона и формирования управляющего воздействия. В рамках курсовой работы эти сведения нужны для объяснения назначения датчика и того, какие параметры выводятся в телеметрический контур.

Интегрирование угловой скорости гироскопа описывается выражением:

angle_gyro(t) = angle_gyro(t - dt) + rate_gyro(t) * dt

Оценка угла по акселерометру для одной оси может быть записана так:

angle_acc = atan2(a_y, a_z)

Для учебного стенда удобен комплементарный фильтр, объединяющий быструю динамику гироскопа и долгосрочную коррекцию акселерометра:

angle(t) = alpha * (angle(t - dt) + gyro(t) * dt) + (1 - alpha) * angle_acc(t)

В контрольной конфигурации использовались параметры alpha = 0.98 и dt = 20 мс. Эти значения позволяют получить устойчивое обновление оценки угла с частотой, близкой к 50 Гц, и хорошо подходят для первичной отладки стенда.

Управляющее воздействие регулятора записывается в стандартном виде:

e(t) = angle_target(t) - angle(t)

u(t) = Kp * e(t) + Ki * integral(e(t) dt) + Kd * de(t) / dt

Для защиты механики и снижения риска резких движений управляющее воздействие ограничивается:

u_limited(t) = min(max(u(t), u_min), u_max)

Параметр | Значение | Комментарий
Kp | 2.00 | Пропорциональная реакция на ошибку угла.
Ki | 0.10 | Ограниченная компенсация статической ошибки.
Kd | 0.50 | Демпфирование быстрых изменений.
dead_zone | ±1.0° | Мертвая зона для подавления реакции на шум.
u_max | ±50 шаг/с | Ограничение управляющего воздействия.
dt | 20 мс | Период дискретизации контура.

# Приложение Г. Программа испытаний и контрольные результаты

Испытания проводятся по уровням, чтобы локализовать ошибки до конкретного узла. Такой порядок позволяет отдельно проверить электрическую часть, датчик, прошивку, телеметрию, сеть, пользовательский интерфейс и исполнительный механизм.

Испытание | Методика | Контрольный результат
Проверка питания | Измерить напряжение логической части и питания моторов, проверить отсутствие короткого замыкания между VCC и GND. | Напряжения соответствуют допустимым уровням модулей, общий GND подключен.
Проверка IMU | Запустить прошивку, выполнить I2C scan и прочитать WHO_AM_I. | Адрес 0x68 обнаружен, WHO_AM_I = 0x71, значения accel/gyro обновляются.
Проверка телеметрии | Открыть поток сообщений и убедиться, что состояние публикуется регулярно. | Публикуются блоки system, mpu, stepper/actuator и wifi.
Проверка WebSocket | Открыть web-интерфейс и наблюдать обновление состояния. | Интерфейс рассчитан на push-обновления и отображает состояние без ручного разбора UART.
Проверка команд | Отправить Stop, Forward, Reverse, Step +, Step -, Faster, Slower. | Команды принимаются, Stop возвращает стенд в безопасное состояние.
Проверка UI | Открыть Overview, Control, Console и motor pad. | Оператор видит телеметрию, события и элементы ручного управления.
Проверка корпуса | Сопоставить геометрию корпуса с размещением платы, моторов и проводов. | Сферический элемент изготовлен и пригоден как физическая основа прототипа.

Метрика | Значение | Интерпретация
I2C address | 0x68 | Датчик найден на ожидаемом адресе.
WHO_AM_I | 0x71 | Модуль идентифицирован как MPU-9250.
Частота телеметрии | 48.4 Гц | Близко к целевому уровню 50 Гц.
Объем телеметрии | 2179 сообщений за 45.0 с | Поток данных стабильно обновляется.
RMS в покое | 0.033° | Шумовая составляющая в покое мала для учебного стенда.
Средняя абсолютная ошибка в покое | 0.148° | Подтверждает стабильность измерительного контура.
Максимальная ошибка в покое | 0.25° | Значение находится в приемлемом диапазоне для демонстрационного прототипа.

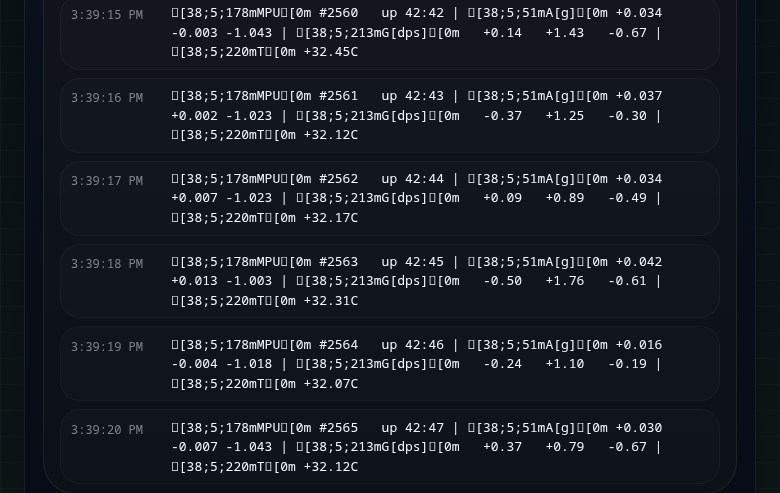
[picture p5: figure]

Рисунок Г.1 - Пример диагностического вывода телеметрии

# Приложение Д. Механическая часть и 3D-печатный корпус

Механическая часть выполнена как сферический корпусной элемент. Для прототипа это рациональное решение, так как корпус можно быстро адаптировать под размеры платы, моторов, проводов, крепежа и батарейного отсека.

Параметр | Значение
Тип корпуса | Сферический элемент прототипа
Внешний диаметр | 210 мм
Высота | 210 мм
Толщина стенки | 3 мм
Материал | PLA
Метод изготовления | FDM-печать
Принтер | Anycubic Kobra 2 Neo
Слайсер | Ultimaker Cura 5.8
Высота слоя | 0.2 мм
Заполнение | 20%
Крышка | Байонетное соединение с поворотом на 30°
Файл модели | fiish.blend / fiish.stl

Инженерные критерии корпуса: доступность разъемов, возможность обслуживания, отсутствие контакта проводов с подвижными элементами, размещение датчика в понятной ориентации относительно корпуса, фиксация платы без короткого замыкания и достаточная жесткость для повторяемых испытаний.

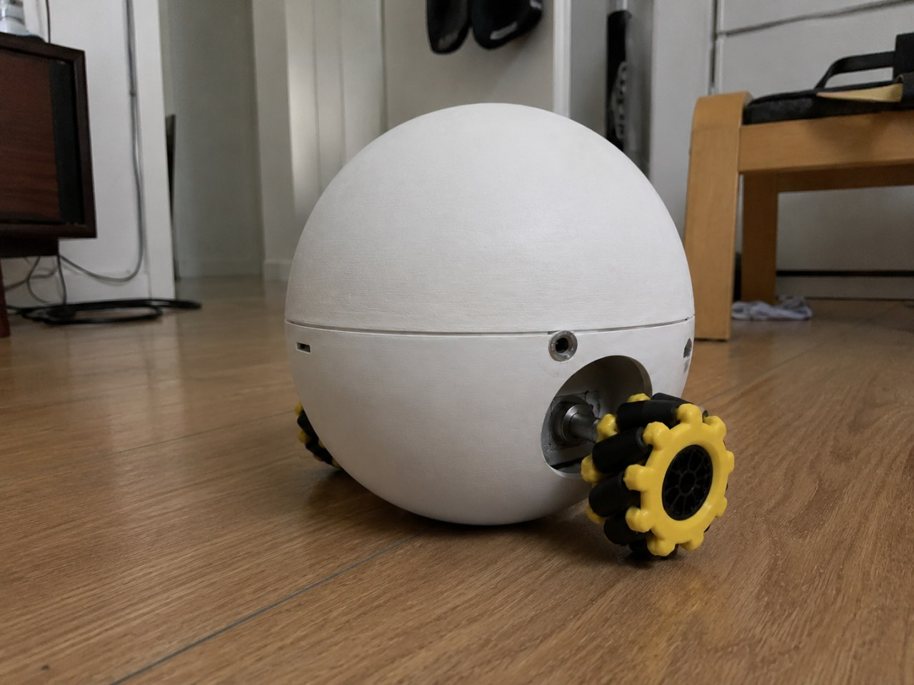
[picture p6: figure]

Рисунок Д.1 - Сферический корпусной элемент прототипа

# Приложение Е. Служебные команды прошивки и запуска

Полная команда прямой прошивки, использованная в контрольной сессии:

python esptool.py --chip esp32p4 -p /dev/ttyUSB0 -b 460800 --before default_reset --after hard_reset write_flash --flash_mode dio --flash_size 16MB --flash_freq 80m 0x2000 bootloader/bootloader.bin 0x8000 partition_table/partition-table.bin 0x10000 p4_lab.bin

Контрольные признаки успешной загрузки: Chip is ESP32-P4, Hash of data verified, Hard resetting via RTS pin. После перезапуска в диагностическом выводе проверяются режим Stop, обнаружение IMU и публикация телеметрии.

Сценарий | Команда / действие | Ожидаемый признак
Запуск стенда | Подключить плату по UART и открыть монитор порта 115200 бод. | Появляется стартовый диагностический вывод.
Проверка IMU | Дождаться сканирования I2C. | В телеметрии указаны address="0x68" и whoami="0x71".
Безопасная остановка | Отправить Stop или сервисную команду остановки. | Режим привода возвращается в Stop.
Освобождение каналов | Отправить Release coils. | Исполнительный узел разгружается.
Проверка UI | Открыть web-пульт оператора. | Отображаются состояние, телеметрия и элементы управления.

# Приложение Ж. Иллюстративные материалы

Ниже собраны изображения, используемые как подтверждающие материалы для защиты: карта выводов, стендовая сборка, фрагменты интерфейса и механический корпус.

# Приложение З. Ссылка на репозиторий

https://github.com/goringich/ESP32-P4-M3#

Рисунок Ж.1 - Карта выводов платы

Рисунок Ж.2 - Открытый аппаратный стенд

Рисунок Ж.3 - Экран телеметрии

Рисунок Ж.4 - Экран ручного управления

Рисунок Ж.5 - Физический корпусной элемент

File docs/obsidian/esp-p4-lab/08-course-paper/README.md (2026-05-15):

# Материалы для курсовой

Этот раздел предназначен не для низкоуровневой навигации по исходникам, а для подготовки связного инженерного текста по проекту. Здесь собраны страницы, которые можно почти напрямую использовать как основу для введения, аналитической части, архитектурной главы и заключения курсовой работы.

## Для чего нужен этот раздел

В остальной документации акцент сделан на точном описании исходников: кто кого вызывает, где лежит компонент, какие структуры формируют JSON, как устроен tick-loop. Для курсовой этого недостаточно. Нужен еще один слой — смысловой:

- какие технологии применены;
- почему архитектура выбрана именно такой;
- какие инженерные компромиссы уже есть в текущей версии;
- какие ограничения имеет прототип;
- как проект можно развивать дальше.

Именно этот слой и собран здесь.

## Состав раздела

- [[08-course-paper/Technologies and stack]]
- [[08-course-paper/Engineering decisions]]
- [[08-course-paper/Current limitations]]
- [[08-course-paper/Future development]]

## Как использовать при написании курсовой

Практический маршрут обычно такой:

1. Из `00-index` и `02-architecture` взять фактическую структуру системы.
2. Из `03-components` и `04-functions` взять точные технические детали.
3. Из этого раздела взять связующие объяснения: зачем используются конкретные технологии, почему модули разделены именно так, какие решения уже приняты и какие ограничения остаются.

Тогда итоговый текст будет не пересказом кода, а инженерным описанием проекта.

## На какие разделы опирается этот материал

- [[02-architecture/System overview]]
- [[02-architecture/Boot and main loop]]
- [[02-architecture/WiFi HTTP WebSocket architecture]]
- [[03-components/app component]]
- [[05-config/Configuration overview]]
- [[06-operations/Build and verification]]

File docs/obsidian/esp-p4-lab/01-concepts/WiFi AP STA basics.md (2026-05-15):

# WiFi AP STA basics

## Два режима, которые использует проект

В проекте предусмотрены два практически важных режима работы Wi‑Fi:

- `AP` — ESP создает собственную точку доступа;
- `APSTA` — ESP одновременно поднимает свою точку доступа и подключается к внешнему роутеру как клиент.

Важно: в **текущей конфигурации проекта по умолчанию используется именно `WIFI_MODE_AP`**, потому что `CONFIG_APP_WIFI_CONNECT` выключен. Режим `APSTA` включается только при специальной настройке STA-подключения.

## Что означает `AP`

В режиме `AP`:

- ESP создает собственную Wi‑Fi сеть;
- компьютер или телефон может подключиться напрямую к устройству;
- сетевой API доступен без внешнего роутера.

Для лабораторного стенда это особенно удобно: система автономна и не зависит от инфраструктуры помещения.

## Что означает `APSTA`

В режиме `APSTA`:

- ESP все еще держит собственную точку доступа;
- одновременно она подключается к существующей Wi‑Fi сети как клиент;
- появляется возможность обращаться к устройству и через SoftAP, и через внешний роутер.

Это полезно, если устройство нужно встроить в более общую сеть, но не потерять прямой fallback-доступ.

## Зачем в проекте нужны оба варианта

- без роутера можно подключиться напрямую к ESP через ее AP;
- при наличии роутера ESP может быть участником общей сети;
- HTTP и WebSocket API доступны поверх Wi‑Fi;
- UART остается резервным локальным каналом диагностики и управления.

## Какие настройки управляют AP

Точка доступа настраивается через:

- `CONFIG_APP_WIFI_AP_SSID_PREFIX`
- `CONFIG_APP_WIFI_AP_PASSWORD`
- `CONFIG_APP_WIFI_AP_CHANNEL`

## Какие настройки включают STA

STA-подключение включается отдельно через:

- `CONFIG_APP_WIFI_CONNECT`
- `CONFIG_APP_WIFI_SSID`
- `CONFIG_APP_WIFI_PASSWORD`

Только после этого `app_wifi.c` начинает выбирать режим `WIFI_MODE_APSTA`.

См. также:

- [[03-components/app_wifi]]
- [[06-operations/How to enable STA WiFi]]

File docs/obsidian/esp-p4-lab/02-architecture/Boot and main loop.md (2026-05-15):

# Boot and main loop

## Общая идея

В проекте используется очень простая и наглядная модель жизненного цикла:

- один вход в систему через `app_main()`;
- один этап инициализации `app_init()`;
- один бесконечный прикладной цикл `app_tick()`.

Для учебного embedded-проекта это удачная архитектура: она легко объясняется, хорошо наблюдается в логах и не требует множества отдельных задач FreeRTOS ради базовой демонстрации работы системы.

## Стартовая цепочка

Фактическая последовательность запуска такая:

1. ESP-IDF вызывает `app_main()` из `main/main.c`.
2. `app_main()` пишет лог `boot`.
3. `app_main()` вызывает `app_init()`.
4. `app_init()` поднимает подсистемы.
5. После возврата из `app_init()` функция `app_main()` входит в бесконечный цикл.
6. На каждой итерации вызывается `app_tick()`.
7. Между итерациями выполняется `vTaskDelay(pdMS_TO_TICKS(app_tick_delay_ms()))`.

В текущем коде `app_tick_delay_ms()` возвращает `5 ms`, то есть базовый цикл выполняется с частотой порядка 200 Гц, если никакая из подсистем не тормозит выполнение сильнее.

## Почему `main` оставлен минимальным

Файл `main/main.c` сознательно почти пустой. Это полезно по нескольким причинам:

- `main` не превращается в свалку инфраструктурного кода;
- перенос логики между проектами упрощается;
- жизненный цикл приложения читается буквально в нескольких строках;
- вся прикладная композиция сосредоточена в `components/app`.

Для курсовой это хороший пример разделения входной точки и прикладного orchestration-слоя.

## Что делает `app_init()`

`app_init()` отвечает за разовый bringup подсистем.

В текущей реализации он делает:

- настраивает уровни логирования;
- выполняет `i2c_bus_init()`;
- запускает `i2c_bus_scan()`;
- выполняет `app_mpu_whoami_check()`;
- при включенном `CONFIG_APP_WIFI_SMOKE` запускает `app_wifi_smoke_run()`;
- при включенном `CONFIG_APP_MODE_L293D_TEST` запускает `app_stepper_init()`;
- при включенном `CONFIG_APP_NET_ENABLE` и готовой сети вызывает `app_net_start()`.

Здесь видно, что `app_init()` не содержит тяжёлой доменной логики каждой подсистемы. Он только управляет порядком запуска.

## Что делает `app_tick()`

`app_tick()` — это периодический диспетчер фоновой активности.

В текущем коде он может вызывать:

- `app_stepper_tick()` — обслуживание state machine двигателя;
- `app_net_tick()` — WebSocket push-рассылку;
- system telemetry и MPU telemetry, если включен `CONFIG_APP_TICK_LOG`.

### Периодическая телеметрия

При включенном `CONFIG_APP_TICK_LOG` функция раз в секунду:

- обновляет system status;
- печатает `@telemetry` для системы;
- вызывает `app_mpu_pretty_log_line()`;
- в случае ошибки MPU записывает `last_error` в системный статус.

Таким образом, быстрый основной цикл работает каждые `5 ms`, а тяжёлая телеметрия ограничена внутренним периодом `APP_MPU_LOG_PERIOD_MS = 1000 ms`.

## Почему выбран tick-loop, а не набор отдельных задач

У такого подхода есть плюсы:

- проще отладка;
- проще объяснение архитектуры;
- меньше многопоточности и гонок;
- компактнее код для лабораторной работы.

Есть и ограничения:

- подсистемы делят один execution path;
- если одна операция станет слишком долгой, пострадает ритм общего цикла;
- при росте проекта может потребоваться отдельная RTOS-задача для сети, сенсора или управления двигателем.

Для текущего стенда этот компромисс выглядит разумным.

## Практический смысл для проекта

Именно через эту схему объясняется всё дальнейшее поведение:

- почему stepper двигается даже без внешних команд;
- почему WebSocket push идет периодически;
- почему MPU лог появляется раз в секунду;
- почему большинство ошибок отражаются в status-структурах, а не только в логах.

См. также:

- [[04-functions/app_main]]
- [[04-functions/app_init]]
- [[04-functions/app_tick]]
- [[02-architecture/Runtime data flow]]

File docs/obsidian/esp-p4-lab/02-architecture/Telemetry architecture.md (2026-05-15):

# Telemetry architecture

## Зачем в проекте отдельная телеметрическая архитектура

Проект не ограничивается управлением устройствами. Он также делает состояние системы наблюдаемым. Это критически важно для:

- отладки;
- демонстрации работы стенда;
- построения web-интерфейса;
- подготовки материалов для курсовой.

По сути, телеметрия здесь — это отдельный функциональный слой, а не побочный вывод логов.

## Формы телеметрии в проекте

В текущей реализации используются три формы представления состояния:

- `printf`-строки с префиксом `@telemetry`;
- HTTP JSON-ответ;
- WebSocket JSON-broadcast.

Эти три формы решают разные задачи, но опираются на одни и те же источники состояния.

## 1. Логовая машинно-читаемая телеметрия

Формат `@telemetry {...}` используется как мост между обычным логом и структурированными данными.

Такие строки генерируют:

- `app_emit_system_telemetry()` — состояние системы;
- `app_stepper_emit_telemetry()` — состояние двигателя;
- `app_mpu_emit_telemetry_ready()` — успешная телеметрия MPU;
- `app_mpu_emit_telemetry_error()` — ошибка MPU.

### Почему это полезно

- данные остаются видимыми в UART/monitor;
- при этом они уже пригодны для автоматического парсинга;
- можно легко писать внешний скрипт, который собирает телеметрию из логов;
- удобно использовать как промежуточный формат для будущей аналитики.

## 2. HTTP JSON-телеметрия

Функция `app_net_build_json()` собирает единый снимок системы для web API.

В JSON входят разделы:

- `system`;
- `mpu`;
- `i2c`;
- `stepper`;
- `wifi`.

Это делает `GET /api/telemetry` главным endpoint'ом наблюдения за прошивкой.

## 3. WebSocket push-телеметрия

`app_net_tick()` раз в секунду рассылает тот же JSON всем WebSocket-клиентам.

Это уже push-модель, удобная для:

- dashboards;
- live-интерфейсов;
- непрерывного обновления состояния без ручного polling.

## Источники данных телеметрии

Телеметрия строится не из одного глобального объекта, а из нескольких status/snapshot-структур:

- `app_system_status_t`;
- `app_i2c_status_t`;
- `app_mpu_status_t`;
- `app_stepper_snapshot_t`;
- `app_wifi_status_t`.

Это очень сильное архитектурное решение: каждая подсистема отвечает за свой собственный снимок состояния, а сетевой слой лишь сериализует его.

## Что именно попадает в телеметрию

### System

- `uptime_ms`
- `tick`
- `tick_delay_ms`
- `firmware`
- `app_mode`
- `last_error`

### MPU

- `ready`
- `error`
- `address`
- `whoAmI`
- `model`
- `uptimeLabel`
- `accel`
- `gyro`
- `tempC`

### I2C

- `ready`
- `devices`
- `detectedMpuAddress`
- `lastScanSummary`
- `error`

### Stepper

- `mode`
- `sweepState`
- `delayMs`
- `stepsPerSecond`
- `phaseIndex`
- `totalSteps`
- `coilsEnabled`
- `sweepSteps`
- `uartReady`
- `lastCommand`
- GPIO pins

### Wi‑Fi

- `initialized`
- `apStarted`
- `staAttempted`
- `staConnected`
- `apSsid`
- `apIp`
- `staIp`
- `lastError`

## Частота обновления

В проекте телеметрия не обновляется с одинаковой частотой во всех каналах.

- основной цикл идет с задержкой `5 ms`;
- stepper heartbeat и WebSocket push идут примерно раз в `1 s`;
- MPU/system telemetry в `app.c` тоже идет раз в `1 s`.

Это хороший баланс между наблюдаемостью и нагрузкой.

## Важный инженерный нюанс

JSON собирается вручную через `snprintf`, а не через JSON-библиотеку. Для текущей фиксированной схемы это нормально, но есть ограничения:

- нужно следить за размерами буферов;
- экранирование строк ограничено;
- при росте протокола код станет сложнее сопровождать.

Для лабораторного стенда это допустимо и даже удобно: структура ответа прозрачна и легко читается прямо в коде.

## Почему телеметрия делает проект сильнее

Без телеметрии проект был бы просто демонстрацией управления мотором и чтения датчика. С телеметрией он становится:

- наблюдаемой embedded-системой;
- удобным объектом для интеграции с UI;
- хорошим материалом для описания архитектуры данных в курсовой.

См. также:

- [[03-components/app_net]]
- [[03-components/app_stepper]]
- [[03-components/app_wifi]]
- [[04-functions/app_net_build_json]]

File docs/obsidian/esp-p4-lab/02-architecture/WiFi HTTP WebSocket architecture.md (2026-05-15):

# WiFi HTTP WebSocket architecture

## Общая идея

Сетевая архитектура проекта разделена на два компонента:

- `app_wifi.c` — поднимает сетевую среду и хранит Wi‑Fi status;
- `app_net.c` — поднимает HTTP/WebSocket API поверх уже готовой сети.

Это правильное разделение ответственности:

- один слой отвечает за radio/network bringup;
- второй — за прикладной API и транспорт данных.

## Что является опорой архитектуры

Сетевой стек нужен в проекте не просто ради "подключиться к Wi‑Fi", а ради трех конкретных задач:

- дать доступ к телеметрии без UART monitor;
- дать удаленное управление двигателем;
- поддержать будущий внешний web-клиент.

Поэтому архитектура строится не вокруг web-страниц, а вокруг API.

## Последовательность запуска

Фактический порядок работы такой:

1. `app_init()` вызывает `app_wifi_smoke_run()`.
2. Wi‑Fi слой инициализирует `NVS`, `esp_netif`, default event loop.
3. Создаются default netif для `STA` и `AP`.
4. Выбирается режим Wi‑Fi:
	- `WIFI_MODE_AP`, если `CONFIG_APP_WIFI_CONNECT` выключен или SSID пустой;
	- `WIFI_MODE_APSTA`, если включен STA-режим и задан SSID.
5. Конфигурируется SoftAP.
6. При необходимости конфигурируется STA.
7. Вызывается `esp_wifi_start()`.
8. В `app.c` при успешном результате ставится `s_network_ready = true`.
9. Если включен `CONFIG_APP_NET_ENABLE` и сеть считается готовой, вызывается `app_net_start()`.
10. HTTP server начинает принимать запросы.
11. В основном цикле `app_tick()` вызывает `app_net_tick()` для периодической WebSocket-рассылки.

Важно: в текущей конфигурации проекта по умолчанию используется именно режим `AP`, а не `APSTA`, потому что `CONFIG_APP_WIFI_CONNECT` не включен.

## Роль SoftAP в архитектуре

SoftAP — это основной текущий способ доступа к устройству.

Почему это удобно:

- для стенда не нужен внешний роутер;
- ноутбук или телефон можно подключить прямо к ESP;
- проверка API не зависит от UART;
- демонстрация проекта становится автономной.

Это особенно удачно для лабораторной работы и защиты: устройство можно показать без привязки к инфраструктуре аудитории.

## Роль режима `APSTA`

Когда включен `CONFIG_APP_WIFI_CONNECT`, архитектура становится гибче:

- ESP продолжает поднимать собственный AP;
- одновременно может подключаться к внешней Wi‑Fi сети как STA;
- после получения IP появляется `sta_ip`, пригодный для интеграции в общую сеть.

То есть одна и та же прошивка может работать и автономно, и в составе более общей сетевой среды.

## HTTP-часть архитектуры

`app_net.c` регистрирует несколько endpoint'ов:

- `GET /api/telemetry`
- `GET /api/wifi`
- `POST /api/command`
- `OPTIONS /*`
- `GET /ws`

Архитектурно это означает разделение на два паттерна:

- pull-модель через REST;
- push-модель через WebSocket.

### Pull-модель

Подходит для:

- ручной проверки через браузер или `curl`;
- отладки;
- простых клиентов без постоянного соединения.

### Push-модель

Подходит для:

- web-dashboard;
- live-обновления статусов;
- минимизации ручного polling со стороны клиента.

## Как сеть получает данные приложения

`app_net_build_json()` не хранит собственное отдельное состояние всех подсистем, а каждый раз собирает его из источников:

- `app_stepper_get_snapshot()`;
- `app_wifi_get_status()`;
- `app_get_system_status()`;
- `app_mpu_get_status()`;
- `app_get_i2c_status()`.

Это делает сетевой слой очень удобным для сопровождения: он выступает как сериализатор текущего состояния системы.

## WebSocket-рассылка

`app_net_tick()` раз в секунду:

- берет список клиентов HTTP server;
- выбирает только WebSocket-клиентов;
- строит единый JSON;
- ставит асинхронную отправку через очередь работ сервера.

Такая схема хороша тем, что отправка не смешивается с логикой чтения состояния и не требует от клиента постоянно опрашивать REST endpoint.

## CORS и интеграция с внешним UI

API сразу сконфигурирован с CORS-заголовками. Это означает, что отдельный web-клиент может быть запущен с другого origin и всё равно обращаться к устройству.

Для проекта это важный шаг в сторону реальной интеграции фронтенда и embedded-устройства.

## Ограничения текущей сетевой архитектуры

- нет аутентификации и авторизации;
- нет TLS;
- JSON формируется вручную;
- нет статической раздачи frontend-ресурсов из этого модуля;
- нет versioned API.

Но для лабораторного стенда этого более чем достаточно: архитектура уже показывает взаимодействие прошивки, сети и внешнего клиента на практическом уровне.

См. также:

- [[03-components/app_wifi]]
- [[03-components/app_net]]
- [[06-operations/Runtime WiFi verification without UART]]
- [[06-operations/API examples]]

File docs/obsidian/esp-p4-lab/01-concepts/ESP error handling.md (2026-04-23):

# ESP error handling

ESP-IDF функции обычно возвращают `esp_err_t`.

В проекте используются основные значения:

- `ESP_OK`: операция успешна.
- `ESP_FAIL`: общая ошибка.
- `ESP_ERR_INVALID_ARG`: неверный аргумент функции.
- `ESP_ERR_INVALID_STATE`: подсистема не инициализирована или уже в другом состоянии.
- `ESP_ERR_NOT_FOUND`: устройство не найдено.
- `ESP_ERR_NOT_SUPPORTED`: возможность не включена в конфиге.
- `ESP_ERR_NO_MEM`: не хватило памяти.
- `ESP_ERR_INVALID_SIZE`: слишком большой буфер или размер.
- `ESP_ERR_TIMEOUT`: таймаут операции.

Для печати человекочитаемого имени ошибки используется:

```c
esp_err_to_name(err)
```

В коде встречаются два стиля:

- вернуть ошибку вызывающему коду;
- использовать `ESP_ERROR_CHECK(...)`, если ошибка считается фатальной на этапе инициализации.

См. [[04-functions/app_wifi_smoke_run]], [[04-functions/i2c_bus_read]], [[04-functions/app_net_start]].

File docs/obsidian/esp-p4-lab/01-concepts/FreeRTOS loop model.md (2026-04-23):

# FreeRTOS loop model

ESP-IDF запускает приложение внутри FreeRTOS. В проекте нет отдельной задачи для каждой подсистемы приложения. Вместо этого используется простой кооперативный цикл:

- `app_main()` вызывает `app_init()`;
- дальше в бесконечном цикле вызывает `app_tick()`;
- между итерациями делает `vTaskDelay(...)`.

Это означает:

- функции `*_tick()` не должны надолго блокировать;
- периодический код проверяет время через `esp_log_timestamp()`;
- HTTP server и Wi-Fi имеют свои внутренние задачи внутри ESP-IDF;
- наше приложение периодически кормит их данными, например через `app_net_tick()`.

Главная задержка цикла задается в `components/app/src/app.c`:

```c
#define APP_MAIN_TICK_MS 5U
```

См. [[04-functions/app_tick]] и [[04-functions/app_tick_delay_ms]].

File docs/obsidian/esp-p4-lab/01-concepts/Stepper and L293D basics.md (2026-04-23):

# Stepper and L293D basics

Шаговый двигатель управляется последовательностью фаз. В проекте фаза описывает четыре входа L293D:

- `IN1`
- `IN2`
- `IN3`
- `IN4`

L293D - это драйвер мотора. Микроконтроллер не должен напрямую питать обмотки двигателя, он только выставляет логические уровни на входах драйвера.

Последовательность фаз в проекте:

```c
{1, 0, 1, 0, "phase A"}
{0, 1, 1, 0, "phase B"}
{0, 1, 0, 1, "phase C"}
{1, 0, 0, 1, "phase D"}
```

Движение вперед - проход по фазам вперед. Движение назад - проход по фазам в обратную сторону.

См. [[03-components/app_stepper]], [[04-functions/app_stepper_step_forward_once]], [[04-functions/app_stepper_step_reverse_once]].

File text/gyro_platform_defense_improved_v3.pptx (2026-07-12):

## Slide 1

Разработка системы
беспроводного управления
гиростабилизируемой платформой

Выполнил: Ким И.Г., студент 3 курса ОП «Компьютерные науки и технологии»

Руководитель: Морозов Н.С., доцент кафедры радиотехники РФФ ННГУ

Факультет информатики, математики и компьютерных наук

Компьютерные науки и
технологии

Нижний Новгород, 2026

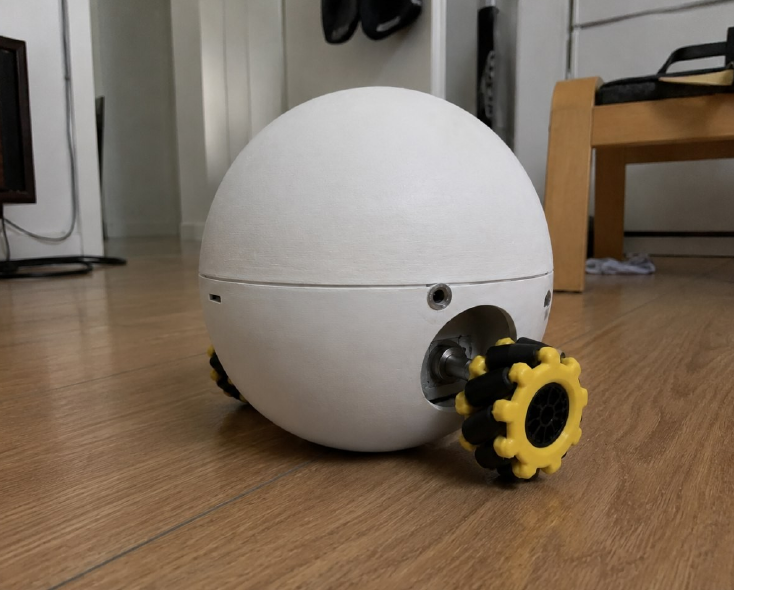
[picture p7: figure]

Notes: Здравствуйте. Тема моей курсовой работы - разработка системы беспроводного управления гиростабилизируемой платформой. В работе я рассматривал не только отдельный датчик или отдельный интерфейс, а полный программно-аппаратный прототип: микроконтроллер, инерциальный датчик, телеметрию, web-пульт, исполнительный контур и механическую основу корпуса. Основная идея работы - сделать такой стенд, который можно проверять по слоям и дальше использовать для настройки стабилизации.

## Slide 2

Компьютерные науки и технологии

Гиростабилизируемая платформа

Введение

2

Зачем нужна система

задача работы на уровне инженерного прототипа

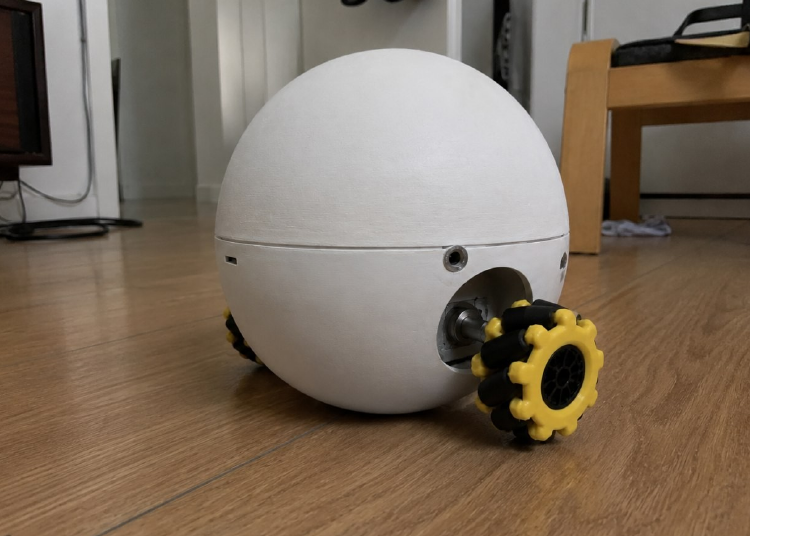
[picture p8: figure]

Гиростабилизируемая платформа должна измерять положение и компенсировать отклонение.
В работе важен не один модуль, а связка: датчик → МК → телеметрия → интерфейс → привод.
Удаленный пульт нужен для диагностики, настройки и безопасного управления стендом.

Цель: разработать прототип беспроводного управления гиростабилизируемой платформой на базе ESP32-P4-M3, MPU-9250, HTTP/WebSocket и 3D-печатного корпуса.

physical prototype

telemetry

remote control

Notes: Проблема состоит в том, что гиростабилизируемая платформа является мехатронной системой. Она должна измерять положение, оценивать отклонение и формировать управляющее воздействие. Для защиты важно показать не абстрактный алгоритм, а цепочку: датчик передает данные на микроконтроллер, микроконтроллер формирует телеметрию, интерфейс показывает состояние, а команды доходят до привода. Поэтому цель работы - разработать прототип беспроводного управления такой платформой на базе ESP32-P4-M3, MPU-9250, HTTP/WebSocket и 3D-печатного корпуса.

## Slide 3

Компьютерные науки и технологии

Гиростабилизируемая платформа

Результат

3

Что сделано в работе

итог не теоретический, а программно-аппаратный

IMU

MPU-9250 по I2C
0x68, WHO_AM_I=0x71

MCU

ESP32-P4-M3
сборка, прошивка, UART

API

HTTP API + WebSocket
JSON-телеметрия

UI

web-пульт
статус, команды, консоль

Корпус

модель + печать
сфера 210 мм, PLA

1

2

3

4

5

Ключевой результат: получился полноценный для курсовой работы прототип с управлением, телеметрией и физической механической основой.

Дальнейшая настройка может выполняться уже на собранной базе; для формата курсовой работы полученного прототипа достаточно.

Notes: В результате работы получился программно-аппаратный прототип. Был подключен IMU-датчик MPU-9250 по I2C, подтвержден адрес 0x68 и идентификатор WHO_AM_I 0x71. Также была подготовлена прошивка под ESP32-P4-M3, реализована телеметрия, HTTP API, WebSocket-обмен, web-интерфейс оператора и физическая механическая основа в виде сферического корпуса. При этом я отдельно фиксирую ограничение: финальная доводка коэффициентов стабилизации требует дополнительных механических испытаний уже после полной сборки.

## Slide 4

Компьютерные науки и технологии

Гиростабилизируемая платформа

Архитектура

4

Слоистая архитектура прототипа

разделение ошибок по уровням: железо, прошивка, сеть, интерфейс

web-пульт: Overview / Control / Console / motor pad

Пользовательский слой

backend-мост: serial / Wi-Fi, нормализация данных

Host-слой

Wi-Fi AP, HTTP API, WebSocket, JSON-состояние

Сетевой слой

инициализация, MPU, телеметрия, команды, безопасный Stop

Embedded-логика

GPIO, I2C, L293D, TT-моторы, питание, корпус

Периферия и механика

Такой подход позволяет отдельно проверять питание, I2C, датчик, телеметрию, API, UI и привод.

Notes: Архитектура сделана слоистой. На нижнем уровне находятся питание, GPIO, I2C, драйвер L293D, TT-моторы и корпус. Выше работает embedded-логика: инициализация, чтение MPU, формирование телеметрии и обработка команд. Дальше идет сетевой слой с Wi-Fi, HTTP API, WebSocket и JSON-состоянием. Над ним расположен backend-мост, который нормализует данные, и frontend-пульт оператора. Такое разделение нужно для отладки: если система ведет себя неправильно, можно отдельно проверить питание, отдельно I2C, отдельно датчик, отдельно API, UI и привод.

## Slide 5

Компьютерные науки и технологии

Гиростабилизируемая платформа

Аппаратная часть

5

Стенд и подключение датчика

минимальная проверка железа перед стабилизацией

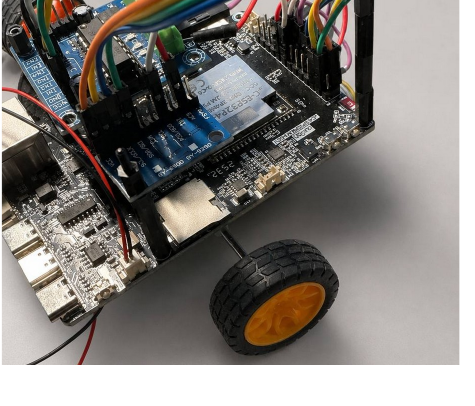
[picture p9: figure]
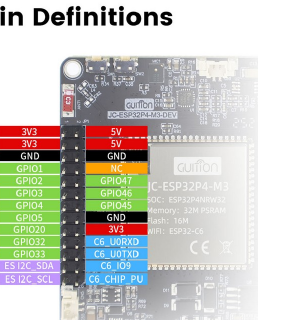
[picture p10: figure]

Линия

Подключение

SDA/SDI

GPIO1

SCL/SCLK

GPIO2

AD0/SDO

NCS

GND → 0x68

3.3 В → I2C

WHO_AM_I

0x71

Условие первичной готовности: I2C scan видит 0x68 и чтение WHO_AM_I возвращает 0x71. Без этого переходить к регулятору нельзя.

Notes: Первым критичным результатом была проверка аппаратного подключения. Датчик GY-9250 или MPU-9250 подключался по I2C: SDA на GPIO1, SCL на GPIO2, AD0 на землю для адреса 0x68, а NCS на 3.3 В для режима I2C. Успешным состоянием я считаю два условия одновременно: сканирование шины видит устройство по адресу 0x68, и чтение регистра WHO_AM_I возвращает 0x71. Без такой проверки нельзя переходить к стабилизации, потому что ошибка может быть не в алгоритме, а в проводах, питании или режиме датчика.

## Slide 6

Компьютерные науки и технологии

Гиростабилизируемая платформа

Удаленное управление

6

Web-пульт оператора и телеметрия

интерфейс нужен как диагностический инструмент, а не как декоративный экран

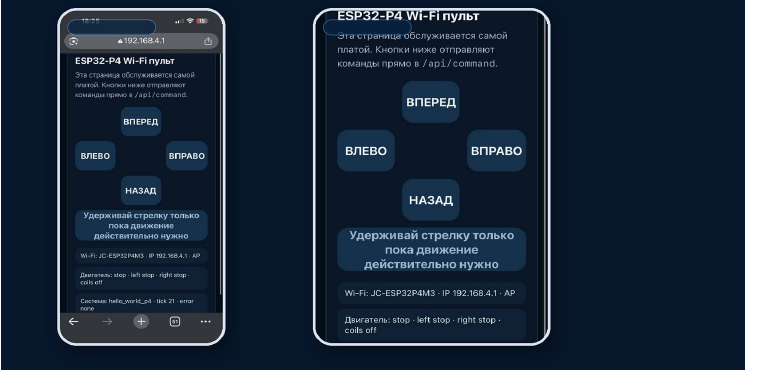
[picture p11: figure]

Endpoint

GET /api/telemetry

Назначение

состояние системы и IMU

GET /api/wifi

статус беспроводного интерфейса

POST /api/command

команды Stop / Forward / Reverse

GET /ws

поток событий и обновлений

~100 мс

задержка команды

48.4 Гц

частота телеметрии

Stop

безопасное состояние

Безопасное правило: команда Stop должна быть доступна всегда; при ошибке связи или датчика привод переводится в безопасное состояние.

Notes: Следующий слой - удаленное управление. Интерфейс здесь не декоративный, а диагностический. Через GET /api/telemetry можно получить состояние системы и IMU, через GET /api/wifi - состояние беспроводного интерфейса, через POST /api/command - передать команды Stop, Forward или Reverse, а через WebSocket - получать поток событий. Главное безопасное правило: команда Stop должна быть доступна всегда. Если связь или датчик работают нестабильно, привод должен переводиться в безопасное состояние.

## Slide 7

Компьютерные науки и технологии

Гиростабилизируемая платформа

Стабилизация

7

Алгоритм оценки угла и ПИД-регулятор

быстрый контур должен выполняться локально на микроконтроллере

акселерометр
+ гироскоп

данные IMU

комплементарный
фильтр

угол

ошибка
цель - угол

e(t)

ПИД
воздействие

u(t)

драйвер
+ моторы

L293D

angle = α · (angle + gyro · dt) + (1 - α) · angle_acc

α = 0.98, dt = 20 мс

u = Kp · e + Ki · ∫e dt + Kd · de/dt

Kp = 2.00, Ki = 0.10, Kd = 0.50

Wi-Fi не должен замыкать быстрый контур управления. Frontend включает режим, меняет параметры и показывает телеметрию. Расчет управляющего воздействия остается в embedded-части.

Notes: Для оценки угла используется сочетание акселерометра и гироскопа. Гироскоп хорошо отражает быстрые изменения, но при интегрировании накапливает дрейф. Акселерометр дает долгосрочную привязку к направлению силы тяжести, но чувствителен к шумам и ускорениям. Поэтому в работе заложен комплементарный фильтр, где alpha равно 0.98, а период дискретизации - 20 миллисекунд. После оценки угла считается ошибка относительно целевого положения, а управляющее воздействие формируется ПИД-регулятором с начальными коэффициентами Kp 2.0, Ki 0.1 и Kd 0.5.

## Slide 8

Компьютерные науки и технологии

Гиростабилизируемая платформа

Контур управления

8

Как команда превращается в движение

логика работы без зависимости стабилизации от браузера

Frontend

режим, параметры, команды

Backend / API

маршрутизация и нормализация

ESP32-P4-M3

быстрый локальный контур

Привод

воздействие на платформу

Пульт не считает управляющее воздействие. Он только включает режимы, отправляет параметры и отображает состояние.

Алгоритм стабилизации остается на микроконтроллере, потому что только локальный контур может быть достаточно предсказуемым.

наблюдаемость: угол → ошибка → воздействие → состояние привода

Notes: Важно, что быстрый контур стабилизации не должен замыкаться через браузер или backend. Wi-Fi нужен для включения режима, настройки параметров и просмотра телеметрии, но расчет управляющего воздействия должен оставаться локально на микроконтроллере. Иначе задержки сети будут напрямую влиять на устойчивость системы. Поэтому правильная логика такая: frontend отправляет режим и параметры, embedded-часть выполняет быстрый контур, а обратно отдает угол, ошибку, управляющее воздействие и состояние привода.

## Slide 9

Компьютерные науки и технологии

Гиростабилизируемая платформа

Испытания

9

Результаты стендовых испытаний

проверены ключевые узлы программно-аппаратного прототипа

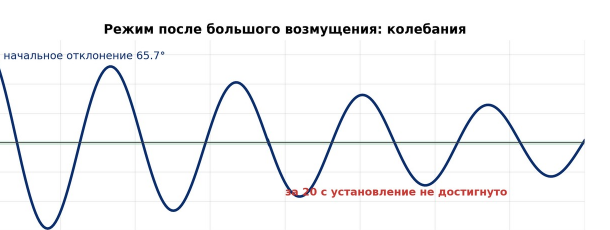
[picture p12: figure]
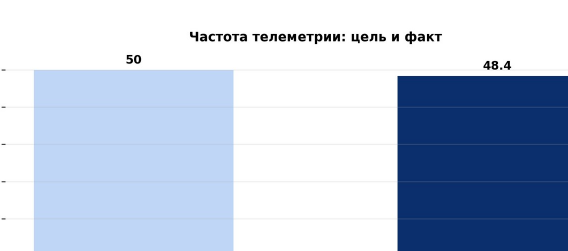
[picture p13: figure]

Метрика

Результат

Вывод: измерение, телеметрия и командная цепочка показывают, что прототип решает задачу курсовой работы. Небольшая дальнейшая настройка относится уже к развитию стенда.

Точность в покое

Средняя ошибка

RMS = 0.033°

0.148°

Частота телеметрии

Большое возмущение

48.4 Гц

65.7°

После возмущения

колебательный режим

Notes: В испытаниях я проверял не промышленную стабилизацию, а работоспособность ключевой цепочки. Подтверждено чтение MPU-9250, обновление телеметрии около 48.4 Гц, прохождение команд до исполнительного контура и отображение состояния в интерфейсе. В покое измерения показали малую ошибку, но после большого возмущения система переходит в колебательный режим. Это ожидаемый результат для прототипа без финальной механической настройки коэффициентов и центра масс.

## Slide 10

Компьютерные науки и технологии

Гиростабилизируемая платформа

Выводы

10

Итоги работы

результат достаточен для курсовой: собрана проверяемая основа системы

Создан программно-аппаратный прототип с измерением, телеметрией, UI и физической механической основой.

измерение

MPU-9250, I2C, WHO_AM_I

1

управление

команды, безопасный Stop

2

наблюдаемость

телеметрия, API, WebSocket

3

механика

3D-корпус и стенд

4

Спасибо за внимание

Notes: Итог работы - создан программно-аппаратный прототип системы беспроводного управления гиростабилизируемой платформой. В нем есть измерение, телеметрия, удаленный интерфейс, команды управления, безопасный режим остановки и физическая механическая база. Практическая ценность в том, что этот стенд можно использовать для дальнейшей настройки стабилизации, подбора коэффициентов и развития уже более точного мехатронного прототипа. Спасибо за внимание.

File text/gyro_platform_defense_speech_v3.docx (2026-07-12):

Текст защиты курсовой работы
«Разработка системы беспроводного управления гиростабилизируемой платформой»

Ориентир: 6-8 минут спокойного выступления.

## Слайд 1. Титульный слайд

Здравствуйте. Тема моей курсовой работы - разработка системы беспроводного управления гиростабилизируемой платформой. В работе я рассматривал не только отдельный датчик или отдельный интерфейс, а полный программно-аппаратный прототип: микроконтроллер, инерциальный датчик, телеметрию, web-пульт, исполнительный контур и механическую основу корпуса. Основная идея работы - сделать такой стенд, который можно проверять по слоям и дальше использовать для настройки стабилизации.

## Слайд 2. Зачем нужна система

Проблема состоит в том, что гиростабилизируемая платформа является мехатронной системой. Она должна измерять положение, оценивать отклонение и формировать управляющее воздействие. В работе рассматривается не абстрактный алгоритм, а связанная инженерная цепочка: датчик передает данные на микроконтроллер, микроконтроллер формирует телеметрию, интерфейс отображает состояние, а команды доходят до привода. Поэтому цель работы - разработать прототип беспроводного управления такой платформой на базе ESP32-P4-M3, MPU-9250, HTTP/WebSocket и 3D-печатного корпуса.

## Слайд 3. Что сделано в работе

В результате работы получился программно-аппаратный прототип. Был подключен IMU-датчик MPU-9250 по I2C, подтвержден адрес 0x68 и идентификатор WHO_AM_I 0x71. Также была подготовлена прошивка под ESP32-P4-M3, реализована телеметрия, HTTP API, WebSocket-обмен, web-интерфейс оператора и физическая механическая основа в виде сферического корпуса. При этом я отдельно фиксирую ограничение: финальная доводка коэффициентов стабилизации требует дополнительных механических испытаний уже после полной сборки.

## Слайд 4. Слоистая архитектура прототипа

Архитектура сделана слоистой. На нижнем уровне находятся питание, GPIO, I2C, драйвер L293D, TT-моторы и корпус. Выше работает embedded-логика: инициализация, чтение MPU, формирование телеметрии и обработка команд. Дальше идет сетевой слой с Wi-Fi, HTTP API, WebSocket и JSON-состоянием. Над ним расположен backend-мост, который нормализует данные, и frontend-пульт оператора. Такое разделение нужно для отладки: если система ведет себя неправильно, можно отдельно проверить питание, отдельно I2C, отдельно датчик, отдельно API, UI и привод.

## Слайд 5. Стенд и подключение датчика

Первым критичным результатом была проверка аппаратного подключения. Датчик GY-9250 или MPU-9250 подключался по I2C: SDA на GPIO1, SCL на GPIO2, AD0 на землю для адреса 0x68, а NCS на 3.3 В для режима I2C. Успешным состоянием я считаю два условия одновременно: сканирование шины видит устройство по адресу 0x68, и чтение регистра WHO_AM_I возвращает 0x71. Без такой проверки нельзя переходить к стабилизации, потому что ошибка может быть не в алгоритме, а в проводах, питании или режиме датчика.

## Слайд 6. Web-пульт оператора и телеметрия

Следующий слой - удаленное управление. Интерфейс здесь не декоративный, а диагностический. Через GET /api/telemetry можно получить состояние системы и IMU, через GET /api/wifi - состояние беспроводного интерфейса, через POST /api/command - передать команды Stop, Forward или Reverse, а через WebSocket - получать поток событий. Главное безопасное правило: команда Stop должна быть доступна всегда. Если связь или датчик работают нестабильно, привод должен переводиться в безопасное состояние.

## Слайд 7. Алгоритм оценки угла и ПИД-регулятор

Для оценки угла используется сочетание акселерометра и гироскопа. Гироскоп хорошо отражает быстрые изменения, но при интегрировании накапливает дрейф. Акселерометр дает долгосрочную привязку к направлению силы тяжести, но чувствителен к шумам и ускорениям. Поэтому в работе заложен комплементарный фильтр, где alpha равно 0.98, а период дискретизации - 20 миллисекунд. После оценки угла считается ошибка относительно целевого положения, а управляющее воздействие формируется ПИД-регулятором с начальными коэффициентами Kp 2.0, Ki 0.1 и Kd 0.5.

## Слайд 8. Как команда превращается в движение

Важно, что быстрый контур стабилизации не должен замыкаться через браузер или backend. Wi-Fi нужен для включения режима, настройки параметров и просмотра телеметрии, но расчет управляющего воздействия должен оставаться локально на микроконтроллере. Иначе задержки сети будут напрямую влиять на устойчивость системы. Поэтому правильная логика такая: frontend отправляет режим и параметры, embedded-часть выполняет быстрый контур, а обратно отдает угол, ошибку, управляющее воздействие и состояние привода.

## Слайд 9. Результаты стендовых испытаний

В испытаниях я проверял не промышленную стабилизацию, а работоспособность ключевой цепочки. Подтверждено чтение MPU-9250, обновление телеметрии около 48.4 Гц, прохождение команд до исполнительного контура и отображение состояния в интерфейсе. В покое измерения показали малую ошибку, но после большого возмущения система переходит в колебательный режим. Это ожидаемый результат для прототипа без финальной механической настройки коэффициентов и центра масс.

## Слайд 10. Итоги работы

В завершение отмечу, что в рамках курсовой работы был получен достаточный инженерный результат: IMU, телеметрия, команды, UI и физическая основа корпуса объединены в единый прототип. Дальнейшее развитие связано с более точной механической настройкой, подбором коэффициентов регулятора и расширенными испытаниями, но базовая цель работы выполнена. Такой вывод корректно фиксирует уровень результата: создана проверяемая инженерная основа системы.

## Слайд 11. Итоги работы

Итог работы - создан программно-аппаратный прототип системы беспроводного управления гиростабилизируемой платформой. В нем есть измерение, телеметрия, удаленный интерфейс, команды управления, безопасный режим остановки и физическая механическая база. Практическая ценность в том, что этот стенд можно использовать для дальнейшей настройки стабилизации, подбора коэффициентов и развития уже более точного мехатронного прототипа. Спасибо за внимание.

# Короткие ответы на возможные вопросы

Почему не Bluetooth?

В текущей архитектуре использован Wi-Fi, потому что он лучше подходит для web-пульта, HTTP API, WebSocket и быстрой диагностики через браузер. Bluetooth можно рассматривать как отдельный транспорт в будущей версии, но он не был основным подтвержденным контуром этой работы.

Почему результат не называется промышленной стабилизацией?

Потому что промышленный результат требует полной механической сборки, точной настройки центра масс, коэффициентов регулятора, PWM-управления и серии повторяемых испытаний. В курсовой подтверждена инженерная основа: датчик, телеметрия, команды, интерфейс и механический прототип.

Зачем нужен web-интерфейс?

Он нужен не для красоты, а для диагностики. Через него можно видеть состояние IMU, связь, режим привода, отправлять безопасные команды и понимать, где именно возникает ошибка.

Почему быстрый контур должен быть на микроконтроллере?

Потому что Wi-Fi и backend не гарантируют стабильную малую задержку. Если стабилизация будет зависеть от браузера, система станет непредсказуемой. Поэтому браузер управляет режимом, а расчет воздействия остается на embedded-части.

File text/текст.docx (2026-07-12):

ФЕДЕРАЛЬНОЕ ГОСУДАРСТВЕННОЕ АВТОНОМНОЕ ОБРАЗОВАТЕЛЬНОЕ УЧРЕЖДЕНИЕ

ВЫСШЕГО ОБРАЗОВАНИЯ

«НАЦИОНАЛЬНЫЙ ИССЛЕДОВАТЕЛЬСКИЙ УНИВЕРСИТЕТ

«ВЫСШАЯ ШКОЛА ЭКОНОМИКИ»

Факультет информатики, математики и компьютерных наук

Программа подготовки бакалавров по направлению
Компьютерные науки и технологии

Ким Игорь Геннадьевич, группа 23КНТ-6

КУРСОВАЯ РАБОТА

«Разработка системы беспроводного управления гиростабилизируемой платформой»

Научный руководитель:

К.ф.-м.н., доцент базовой кафедры

информационных систем и технологий

Улитин Б.И.
Соруководитель:

Доцент кафедры радиотехники РФФ ННГУ

Морозов Никита Сергеевич

Нижний Новгород, 2026

# Оглавление

Введение .................................................................. 4

Цель и задачи работы ...................................................... 6

Роль автора и состав выполненных работ .................................... 8

Глава 1. Исследовательская часть .......................................... 9

1.1. Актуальность и предметная область ................................ 9

1.2. Назначение гиростабилизируемых платформ .......................... 10

1.3. Анализ требований к прототипу .................................... 11

1.4. Анализ технических подходов и аналогов ........................... 12

1.5. Обоснование выбранной аппаратно-программной архитектуры .......... 14

Глава 2. Проектирование системы ........................................... 15

2.1. Общая архитектура системы .....................................… 15

2.2. Аппаратная часть ................................................. 16

2.3. Подсистема инерциальных измерений ................................ 18

2.4. Подсистема исполнительных механизмов ............................. 18

2.5. Беспроводной интерфейс и удаленное управление .................... 20

2.6. Механическая часть и 3D-печатный корпус .......................... 22

2.7. Выводы по проектированию ......................................... 23

Глава 3. Реализация программно-аппаратного прототипа ...................... 23

3.1. Embedded-часть на ESP32-P4-M3 .................................... 23

3.2. Работа с MPU-9250 по I2C ......................................... 24

3.3. Телеметрия, HTTP API и WebSocket ................................. 25

3.4. Backend и frontend станции управления ............................ 26

3.5. Обработка команд управления приводом ............................. 27

3.6. Сборка, прошивка и диагностика ................................... 28

3.7. Реализация механической части .................................... 29

Глава 4. Алгоритмы обработки данных и стабилизации ........................ 30

4.1. Модель обработки измерений IMU ................................... 30

4.2. Оценка угла наклона и фильтрация ................................. 31

4.3. Регулятор компенсации наклона .................................... 31

4.4. Интеграция алгоритма с беспроводным управлением .................. 32

4.5. Область результата в рамках курсовой работы ...................... 33

Глава 5. Испытания и анализ результатов ................................... 33

5.1. Методика испытаний ............................................... 33

5.2. Проверка аппаратных подключений .................................. 34

5.3. Проверка беспроводного интерфейса ................................ 35

5.4. Проверка пользовательского интерфейса ............................ 37

5.5. Испытания механической части ..................................... 38

5.6. Проверка программной основы стабилизации ......................... 39

5.7. Итоги анализа результатов ........................................ 40

6. Безопасность при работе со стендом ..................................... 41

Заключение ................................................................ 43

Список использованных источников .......................................... 44

Приложения ................................................................ 46

# Введение

Системы стабилизации положения относятся к классу программно-аппаратных систем, в которых результат определяется не только качеством отдельного алгоритма, но и согласованной работой механики, датчиков, исполнительных механизмов, микроконтроллера и пользовательского интерфейса. Гиростабилизируемые платформы применяются в робототехнике, мобильных измерительных комплексах, системах ориентации камер, малых беспилотных устройствах и учебных лабораторных стендах. Их задача состоит в том, чтобы измерять текущее положение объекта, оценивать отклонение от требуемого состояния и формировать управляющее воздействие, компенсирующее наклон или внешнее возмущение.

Актуальность выбранной темы связана с тем, что современные встраиваемые системы все чаще строятся как распределенные комплексы: вычислительное ядро работает с датчиками и приводами, а управление, диагностика и визуализация выполняются через беспроводной интерфейс. Такой подход повышает удобство отладки и эксплуатации, но требует продуманной архитектуры обмена данными, устойчивого протокола управления, достаточной частоты телеметрии и понятного пользовательского интерфейса. В учебном проекте это особенно важно, потому что система должна быть не только работоспособной, но и объяснимой: каждый аппаратный и программный узел должен подтверждаться измеряемым параметром, диагностическим сообщением или наблюдаемым поведением.

В рамках данной курсовой работы рассматривается разработка прототипа системы беспроводного управления гиростабилизируемой платформой на базе микроконтроллерной платы JC-ESP32P4-M3 и инерциального датчика GY-9250 / MPU-9250. В проекте реализованы слои подключения IMU по I2C, первичной телеметрии, беспроводного доступа, интерфейса удаленного управления, а также механическая часть в виде напечатанного на 3D-принтере сферического элемента, подготовленного в Blender. Подробные технические сведения вынесены в отдельный файл приложений, а в основной части сохранено описание подтвержденного результата: удаленное подключение, дистанционное управление и вывод телеметрии в пользовательский интерфейс.

Работа относится к проектному типу курсовой работы, поскольку ее результатом является не только теоретический анализ, но и программно-аппаратный прототип. При этом исследовательская часть также является существенной: необходимо проанализировать предметную область, выбрать аппаратную платформу, описать датчики ориентации, способы фильтрации измерений, принципы замкнутого управления и методику проверки результата. Такой формат позволяет показать не отдельный фрагмент кода, а полный инженерный путь от постановки задачи до тестируемого стенда.

# Цель и задачи работы

Целью курсовой работы является разработка и документирование прототипа системы беспроводного управления гиростабилизируемой платформой, включающего аппаратный стенд, подсистему инерциальных измерений, программные модули телеметрии и управления, а также механический корпусной элемент, изготовленный с применением 3D-печати.

Для достижения цели были сформулированы следующие задачи:

• проанализировать предметную область гиростабилизируемых платформ и выделить требования к учебному прототипу;

• выбрать состав аппаратных компонентов и определить их роль в системе;

• реализовать подключение инерциального датчика GY-9250 / MPU-9250 к JC-ESP32P4-M3 по интерфейсу I2C;

• реализовать получение и публикацию телеметрии датчика в формате, пригодном для дальнейшей обработки и визуализации;

• разработать беспроводной контур удаленного управления и диагностики на базе HTTP API и WebSocket;

• подготовить пользовательский интерфейс для отображения состояния системы и передачи команд исполнительному механизму;

• разработать и изготовить механическую часть прототипа в виде сферического элемента, смоделированного в Blender и распечатанного на 3D-принтере;

• описать программную основу обработки данных IMU, контур удаленного управления и логику безопасного управления исполнительным механизмом;

• сформировать программу испытаний, провести проверку ключевых подсистем и зафиксировать полученные результаты.

Объектом работы является программно-аппаратная система управления положением платформы. Предметом работы являются методы беспроводного управления, обработки данных инерциального датчика и организации программной архитектуры прототипа гиростабилизации. Практическая значимость работы состоит в создании стенда, который может быть использован для дальнейших экспериментов с алгоритмами стабилизации, анализа телеметрии и отладки встраиваемого программного обеспечения.

# Роль автора и состав выполненных работ

В рамках проекта автор выполнял задачи, связанные с интеграцией аппаратных модулей, программной архитектурой embedded-части, организацией удаленного управления и подготовкой физического прототипа. Основной фокус работы был направлен на то, чтобы связать отдельные компоненты системы в проверяемую цепочку: датчик ориентации - микроконтроллер - телеметрия - интерфейс оператора - команды управления - физический стенд.

К выполненным работам относятся: анализ подключений GY-9250 / MPU-9250, настройка линий I2C, проверка адреса устройства, чтение идентификатора WHO_AM_I, подготовка диагностических сообщений, разработка модулей телеметрии, настройка сетевого взаимодействия, разработка интерфейса управления и изготовление сферического элемента корпуса. Отдельно была проведена работа по проектированию механической части в Blender и последующей 3D-печати, что позволило перейти от чисто программного прототипа к физически собираемому стенду.

Границы ответственности в работе определены следующим образом: в основной части описываются подтвержденные результаты курсового проекта, а детальные служебные сведения по подключению, прошивке и испытаниям вынесены в отдельный файл приложений.

# Глава 1. Исследовательская часть

## 1.1. Актуальность и предметная область

Гиростабилизируемая платформа является примером мехатронной системы, в которой одновременно решаются задачи измерения, вычисления, управления и физического воздействия на объект. В отличие от простых систем дистанционного управления, где команда оператора напрямую передается исполнительному механизму, в стабилизируемой системе требуется учитывать текущее состояние платформы. Система должна понимать, как она ориентирована в пространстве, какой угол отклонения присутствует и какое воздействие необходимо сформировать для компенсации.

Ключевая особенность таких платформ состоит в замкнутом контуре управления. Датчик ориентации измеряет ускорения и угловые скорости, программный модуль оценивает положение, регулятор вычисляет управляющее воздействие, а привод изменяет состояние механической части. После этого датчик снова фиксирует новое положение. Если этот цикл работает достаточно быстро и устойчиво, платформа способна сопротивляться внешним возмущениям. Если же один из слоев работает неправильно, система становится нестабильной или непредсказуемой.

Для учебного проекта гиростабилизируемая платформа удобна тем, что в ней наглядно проявляются все уровни embedded-разработки. На электрическом уровне нужно обеспечить питание, общую землю, корректные логические уровни и надежную шину I2C. На уровне периферии микроконтроллера нужно настроить GPIO, I2C, сетевой стек и тайминги. На уровне прошивки требуется организовать чтение датчика, обработку ошибок и публикацию телеметрии. На уровне прикладного программного обеспечения необходимо отобразить данные пользователю и передать команды управления. На механическом уровне нужно обеспечить возможность установки платы, датчика, привода и корпуса.

Тем самым данная курсовая работа находится на стыке робототехники, микроконтроллерного программирования, сетевых протоколов, интерфейсной разработки и быстрого прототипирования. Это делает проект показательным с точки зрения инженерной подготовки: результат нельзя получить только написанием программы или только сборкой схемы. Необходима проверяемая интеграция всех слоев системы.

## 1.2. Назначение гиростабилизируемых платформ

Гиростабилизируемые платформы применяются там, где требуется сохранять ориентацию полезной нагрузки при движении основания. В малых робототехнических системах это может быть стабилизация камеры, датчика расстояния, антенны или измерительного модуля. В более сложных системах используются многокоординатные подвесы, которые компенсируют повороты по нескольким осям. С точки зрения теории автоматического управления такая система рассматривается как замкнутый контур с датчиком, регулятором и исполнительным механизмом [14; 17]. В учебном прототипе основное внимание уделяется не промышленной точности, а построению принципиально правильной архитектуры управления.

С функциональной точки зрения стабилизируемая платформа должна выполнять четыре действия. Во-первых, она должна измерять свое состояние. Во-вторых, она должна преобразовывать сырые измерения в физически интерпретируемые параметры: угол, скорость, направление отклонения. В-третьих, она должна вычислять корректирующее воздействие. В-четвертых, она должна воздействовать на исполнительный механизм и контролировать результат. Именно эта цепочка определяет содержание проектной части работы.

Важной особенностью является то, что стабилизация зависит от частоты обновления данных. Если измерения поступают редко, регулятор получает устаревшую информацию. Если команды передаются с большой задержкой, механическая часть не успевает компенсировать наклон. Если телеметрия нестабильна, оператор не может оценить состояние системы. Поэтому в работе рассматриваются не только сами алгоритмы, но и инфраструктура передачи данных: HTTP API, WebSocket, backend-мост и frontend-интерфейс.

## 1.3. Анализ требований к прототипу

Требования к прототипу можно разделить на функциональные, аппаратные, программные, эксплуатационные и документируемые. Такое разделение важно, потому что курсовая работа оценивает не только наличие работающего устройства, но и полноту обоснования инженерных решений.

Группа требований | Содержание
Функциональные требования | Считывание данных IMU, передача телеметрии, прием команд управления, отображение состояния системы, подготовка контура стабилизации.
Аппаратные требования | Совместимость с JC-ESP32P4-M3, подключение GY-9250 / MPU-9250 по I2C, корректное питание 3.3 В, общий GND, физическая установка внутри корпуса.
Программные требования | Модульная embedded-архитектура, обработка ошибок I2C, сетевой API, журналирование, возможность дальнейшего расширения алгоритма стабилизации.
Эксплуатационные требования | Удобный запуск, возможность наблюдения логов, доступ к интерфейсу управления, наличие методики испытаний.
Документируемые требования | Описание архитектуры, схемы подключений, алгоритмов, испытаний, ограничений и недостающих результатов.

Для текущего этапа проекта наиболее критичными являются требования к наблюдаемости системы. Прототип должен быть устроен так, чтобы любую ошибку можно было локализовать: отдельно проверить питание, отдельно шину I2C, отдельно наличие устройства на адресе 0x68, отдельно чтение WHO_AM_I, отдельно получение телеметрии, отдельно сетевой доступ и отдельно реакцию интерфейса на команды пользователя. Такой подход снижает риск ситуации, когда система «не работает», но неясно, где именно находится ошибка.
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

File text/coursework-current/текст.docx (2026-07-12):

ФЕДЕРАЛЬНОЕ ГОСУДАРСТВЕННОЕ АВТОНОМНОЕ ОБРАЗОВАТЕЛЬНОЕ УЧРЕЖДЕНИЕ

ВЫСШЕГО ОБРАЗОВАНИЯ

«НАЦИОНАЛЬНЫЙ ИССЛЕДОВАТЕЛЬСКИЙ УНИВЕРСИТЕТ

«ВЫСШАЯ ШКОЛА ЭКОНОМИКИ»

Факультет информатики, математики и компьютерных наук

Программа подготовки бакалавров по направлению
Компьютерные науки и технологии

Ким Игорь Геннадьевич, группа 23КНТ-6

КУРСОВАЯ РАБОТА

«Разработка системы беспроводного управления гиростабилизируемой платформой»

Научный руководитель:

Морозов Никита Сергеевич, доцент кафедры радиотехники РФФ ННГУ

Нижний Новгород, 2026

# Оглавление

Введение .................................................................. 4

Цель и задачи работы ...................................................... 5

Роль автора и состав выполненных работ .................................... 6

Глава 1. Исследовательская часть .......................................... 8

1.1. Актуальность и предметная область ................................ 8

1.2. Назначение гиростабилизируемых платформ .......................... 9

1.3. Анализ требований к прототипу .................................... 10

1.4. Анализ технических подходов и аналогов ........................... 11

1.5. Обоснование выбранной аппаратно-программной архитектуры .......... 13

Глава 2. Проектирование системы ........................................... 14

2.1. Общая архитектура системы ........................................ 14

2.2. Аппаратная часть ................................................. 15

2.3. Подсистема инерциальных измерений ................................ 18

2.4. Подсистема исполнительных механизмов ............................. 18

2.5. Беспроводной интерфейс и удаленное управление .................... 20

2.6. Механическая часть и 3D-печатный корпус .......................... 22

2.7. Выводы по проектированию ......................................... 23

Глава 3. Реализация программно-аппаратного прототипа ...................... 23
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

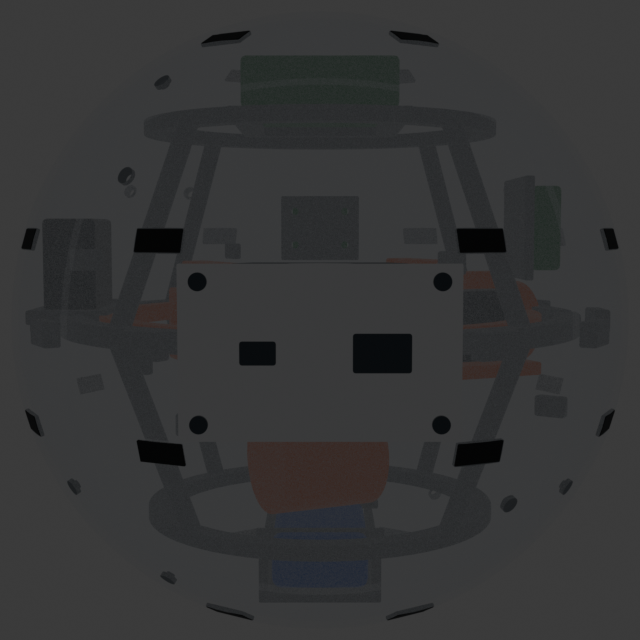
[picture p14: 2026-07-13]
mechanical/spherical_robot/exports/renders/side_view.png

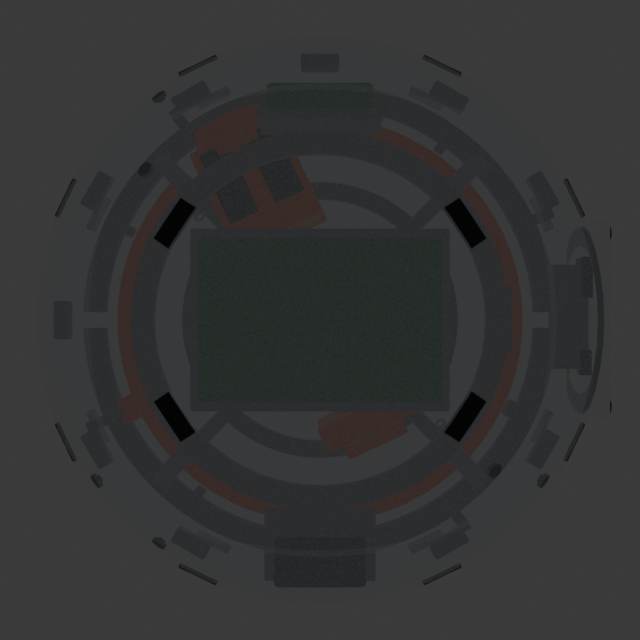
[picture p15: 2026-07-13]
mechanical/spherical_robot/exports/renders/top_view.png

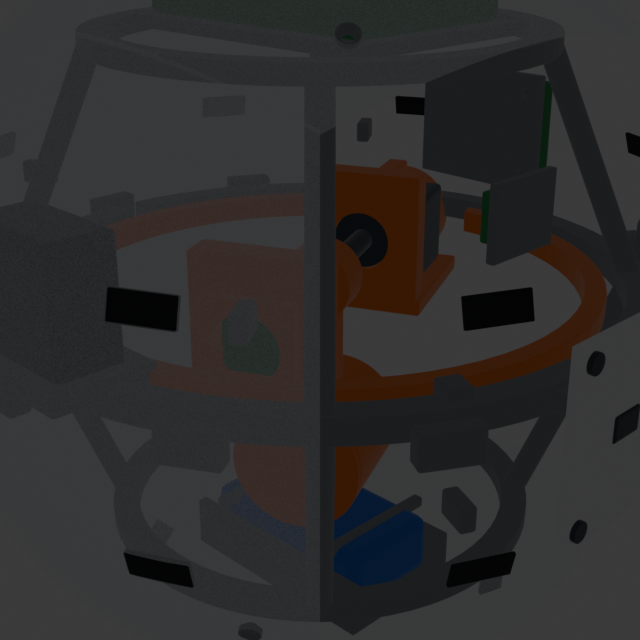
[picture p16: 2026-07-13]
mechanical/spherical_robot/exports/renders/pendulum_closeup.png

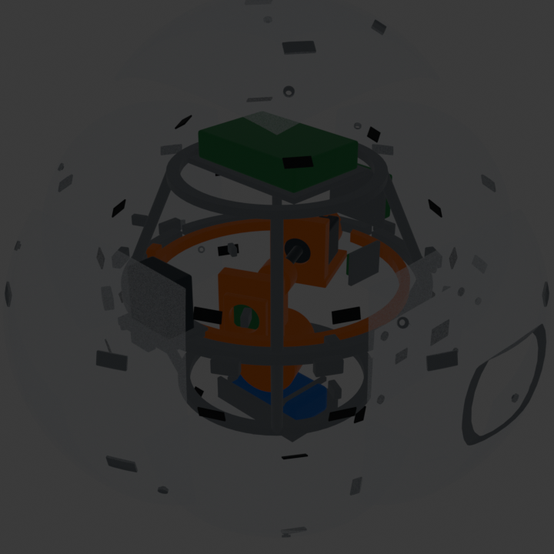
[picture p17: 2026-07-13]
mechanical/spherical_robot/exports/renders/exploded_view.png

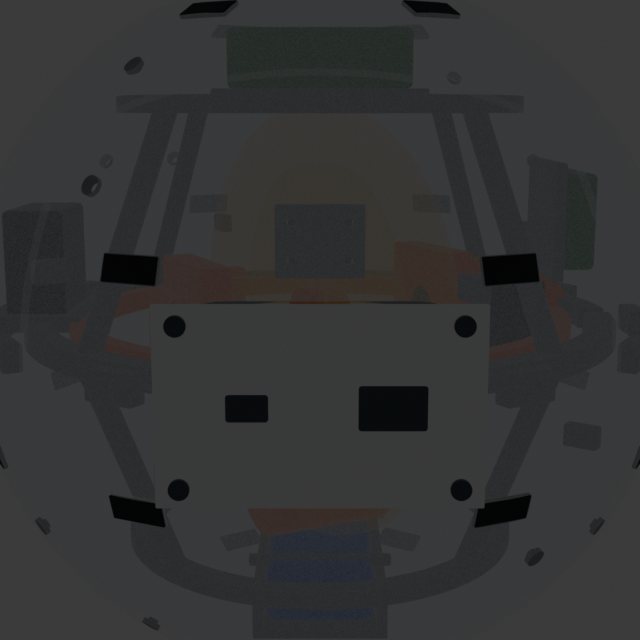
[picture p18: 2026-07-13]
mechanical/spherical_robot/exports/renders/swept_volume.png

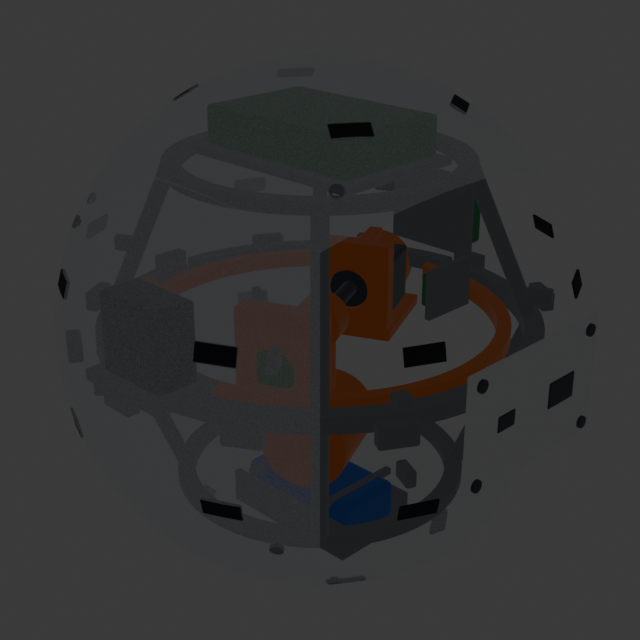
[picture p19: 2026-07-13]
mechanical/spherical_robot/exports/renders/section_view.png

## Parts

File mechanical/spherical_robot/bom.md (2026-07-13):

# BOM — сферический робот P0.1

Конкретные покупные модели не зафиксированы до измерения и проверки характеристик.

| Позиция | Кол-во | Требование |
|---|---:|---|
| DC/BLDC мотор-редуктор маятника с энкодером | 1 | выход около 30 об/мин; ≥0.50 Н·м непрерывно; ≥0.86 Н·м кратковременно; напряжение по батарее; рабочий ток и stall current должны быть подтверждены; металлический выходной вал; энкодер с разрешением для низкой скорости |
| Рулевой привод | 1 | рабочий диапазон не менее ±65°; удерживающий/самотормозящий редуктор предпочтителен; обратная связь угла; съёмный выходной элемент |
| Радиальные подшипники вала | 2 | ориентир-envelope 8×22×7 мм `_PLACEHOLDER`; одинаковая серия; закрытые; окончательная посадка только после coupon |
| Стальной вал | 1 | Ø8×112 мм ориентировочно; прямой, шлифованный; фактический допуск измерить |
| Магнитный или оптический энкодер маятника | 1 | статор на steering frame, ротор/магнит на валу; провода не вращаются |
| ESP32-P4-M3 | 1 | существующая плата; измерить envelope/отверстия/разъёмы |
| MPU-9250 module | 1 | жёсткая фиксация на неподвижном каркасе; вертикальная установка в текущей компоновке |
| Аккумулятор с BMS | 1 | текущий envelope 72×40×22 мм и 220 г `_PLACEHOLDER`; ток разряда выше stall current с запасом; съём через люк 92×58 мм |
| Силовой driver | 1 | напряжение батареи; continuous/peak current двигателя; защита от выбросов и перегрева; размер `_PLACEHOLDER` |
| Главный выключатель | 1 | размыкает питание привода; cutout измерить |
| Зарядный разъём | 1 | ток/напряжение по батарее и заряднику; механическая фиксация к люку |
| Стальной балласт | 1 комплект | варианты 200/300/400 г из шайб, пластин, гаек или бруска; пластик в массу не засчитывается |
| M3 винты с утопленной головкой | ориентир 36 | панели, люк и съёмные узлы; длины подобрать после inserts |
| Латунные термовставки M3 | ориентир 24 | фактический диаметр/длина и pilot hole измерить |
| M3 гайки/Nyloc и шайбы | ориентир 20 | ступица, балласт, mounts, оснастка |
| M2/M2.5 крепёж | по факту плат | только после измерения отверстий плат |
| Ремень аккумулятора | 1–2 | ориентир 15 мм, негорючий/липучка; не пережимать элементы |
| Проводка, гибкая оплётка, разъёмы | комплект | закрепить на fixed frame; ни один провод не проходит через вращающийся маятник |
| TPU 95A | около 24 inserts | сменные распределённые элементы сцепления |

Расчётные требования не заменяют bench test: до установки в шар измерить no-load current, рабочий ток, stall current через ограниченный источник, реальный момент и нагрев выбранного редуктора/driver.

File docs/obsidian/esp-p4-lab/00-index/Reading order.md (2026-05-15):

# Reading order

Этот файл задает не просто список страниц, а несколько разных маршрутов чтения в зависимости от цели.

## Базовый маршрут: быстро понять весь проект

Если нужно получить цельную картину прошивки, лучше идти в таком порядке:

1. [[00-index/README]]
2. [[01-concepts/ESP-IDF basics]]
3. [[01-concepts/FreeRTOS loop model]]
4. [[01-concepts/ESP error handling]]
5. [[01-concepts/WiFi AP STA basics]]
6. [[01-concepts/HTTP and WebSocket basics]]
7. [[01-concepts/I2C basics]]
8. [[01-concepts/Stepper and L293D basics]]
9. [[02-architecture/System overview]]
10. [[02-architecture/Boot and main loop]]
11. [[02-architecture/Runtime data flow]]
12. [[02-architecture/WiFi HTTP WebSocket architecture]]
13. [[02-architecture/UART and network dual control]]
14. [[02-architecture/Telemetry architecture]]
15. [[03-components/app component]]
16. [[03-components/app_wifi]]
17. [[03-components/app_net]]
18. [[03-components/app_stepper]]
19. [[03-components/i2c_bus]]
20. [[03-components/mpu9250]]
21. [[05-config/Configuration overview]]
22. [[06-operations/Build and verification]]

Этот маршрут лучше всего подходит, если нужно потом писать связный обзор проекта для курсовой.

## Маршрут: только сеть и удаленное управление

Если задача — понять Wi‑Fi, HTTP, WebSocket и API, читай:

- [[02-architecture/WiFi HTTP WebSocket architecture]]
- [[02-architecture/UART and network dual control]]
- [[03-components/app_wifi]]
- [[03-components/app_net]]
- [[04-functions/app_wifi_smoke_run]]
- [[04-functions/app_net_start]]
- [[04-functions/app_net_build_json]]
- [[04-functions/app_net_tick]]
- [[06-operations/API examples]]
- [[06-operations/Runtime WiFi verification without UART]]

## Маршрут: только мотор и локальное управление

Если нужно быстро понять stepper и старое UART-управление:

- [[02-architecture/UART and network dual control]]
- [[03-components/app_stepper]]
- [[04-functions/app_stepper_init]]
- [[04-functions/app_stepper_tick]]
- [[04-functions/app_stepper_handle_command]]
- [[04-functions/app_stepper_get_snapshot]]

## Маршрут: только сенсорная часть и I2C

Если нужен MPU/I2C-путь:

- [[01-concepts/I2C basics]]
- [[03-components/i2c_bus]]
- [[03-components/mpu9250]]
- [[04-functions/i2c_bus_init]]
- [[04-functions/i2c_bus_scan]]
- [[04-functions/mpu9250_probe_and_read_whoami]]
- [[04-functions/app_mpu_pretty_init]]
- [[04-functions/app_mpu_pretty_log_line]]

## Когда использовать индексы

После обзорного чтения лучше переходить к индексам:

- [[00-index/Function index]] — если нужна навигация по поведению кода;
- [[00-index/Config index]] — если нужно понять, что задается конфигом;
- [[00-index/Source map]] — если нужно быстро найти физические файлы.

## Практический совет

Для подготовки курсовой лучше читать именно слоями:

1. концепции;
2. архитектура;
3. компоненты;
4. функции;
5. конфигурация;
6. эксплуатация и верификация.

Так текст потом сам собирается в правильную структуру главы. Почти как будто проект сам пишет пояснительную записку, если его достаточно долго читать. Почти.

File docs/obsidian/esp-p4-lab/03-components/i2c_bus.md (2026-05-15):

# i2c_bus

Файл: `components/i2c_bus/src/i2c_bus.c`.

## Назначение компонента

`i2c_bus` — это низкоуровневая обертка над API `i2c_master` из ESP-IDF. Компонент дает остальной прошивке простой и единый способ:

- поднять I2C master bus;
- проверить состояние линий;
- выполнить scan;
- пробовать конкретный адрес;
- читать и писать регистры устройств.

## Почему этот модуль важен

Без него код работы с MPU пришлось бы размазывать по нескольким файлам. Здесь же I2C вынесен в отдельный reusable-слой, что делает архитектуру чище.

## Инициализация шины

`i2c_bus_init()` выполняет несколько полезных шагов:

1. проверяет, не инициализирована ли шина уже;
2. при включенном `CONFIG_I2C_BUS_SELFTEST` запускает self-test линий;
3. читает idle levels на SDA/SCL до подключения периферии I2C;
4. предупреждает, если какая-то линия удерживается в `0`;
5. создает master bus через `i2c_new_master_bus()`;
6. логирует итоговую конфигурацию.

Этот подход полезен для реальной отладки железа: можно рано заметить проблемы с питанием, pull-up резисторами или перепутанными линиями.

## Scan шины

`i2c_bus_scan()` имеет двухступенчатую стратегию:

- сначала быстрый probe только адресов `0x68` и `0x69`;
- затем, если включен `CONFIG_I2C_BUS_SCAN_FULL`, полный перебор диапазона `0x03..0x77`.

Это разумный компромисс:

- для основного сценария с MPU не тратится лишнее время;
- при необходимости можно включить полную диагностику.

Компонент дополнительно считает:

- количество найденных устройств;
- число timeout;
- число остальных ошибок.

## Работа с регистрами

### `i2c_bus_read()`

Выполняет типичную операцию register read:

- открывает временный device handle;
- отправляет адрес регистра;
- читает `out_len` байт ответа;
- удаляет handle устройства.

### `i2c_bus_write()`

Формирует буфер вида:

`[reg][payload...]`

После этого выполняет передачу и освобождает временный device handle.

## Важная особенность реализации

`i2c_bus_read()` и `i2c_bus_write()` каждый раз создают device handle через `i2c_bus_open_device()` и потом удаляют его через `i2c_master_bus_rm_device()`.

Плюсы такого решения:

- простая логика;
- не нужно хранить таблицу открытых устройств;
- меньше риска рассинхронизации состояния устройств в маленьком проекте.

Минусы:

- дополнительный overhead на каждом чтении/записи;
- не лучший выбор для высокочастотного polling в production-сценарии.

Для текущего лабораторного проекта этот компромисс выглядит оправданным.

## Диагностика уровней линий

В модуле есть вспомогательные функции:

- `i2c_bus_read_lines()`;
- `i2c_bus_log_lines()`;
- `i2c_bus_selfcheck_gpio()`.

Они нужны не для прикладной логики, а для инженерной диагностики. Это сильная сторона проекта: разработчик сразу получает больше информации о том, что происходит на физическом уровне шины.

## Ограничения и ограничения буферов

В `i2c_bus_write()` есть маленький статический буфер `uint8_t buf[1 + 16]`, поэтому запись ограничена `16` байтами полезных данных за одну операцию. Для конфигурационных регистров MPU этого достаточно, но для более общих сценариев это нужно учитывать.

## Связь с другими компонентами

- `app.c` использует `i2c_bus_init()`, `i2c_bus_scan()`, `i2c_bus_deinit()`;
- `mpu9250.c` использует `i2c_bus_probe_addr()`, `i2c_bus_read()`, `i2c_bus_write()`;
- `app_mpu_pretty.c` использует `i2c_bus_read()` и `i2c_bus_write()` для чтения регистров MPU.

Именно поэтому `i2c_bus` можно рассматривать как базовый инфраструктурный слой сенсорной подсистемы.

Главные функции:

- [[04-functions/i2c_bus_init]]
- [[04-functions/i2c_bus_deinit]]
- [[04-functions/i2c_bus_scan]]
- [[04-functions/i2c_bus_probe_addr]]
- [[04-functions/i2c_bus_read]]
- [[04-functions/i2c_bus_write]]

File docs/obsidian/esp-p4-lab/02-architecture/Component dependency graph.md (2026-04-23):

# Component dependency graph

Компоненты ESP-IDF:

```text
main
  -> app

app
  -> i2c_bus
  -> mpu9250
  -> esp_driver_gpio
  -> esp_driver_uart
  -> esp_wifi
  -> esp_event
  -> esp_http_server
  -> esp_netif
  -> nvs_flash

mpu9250
  -> i2c_bus

i2c_bus
  -> driver
  -> esp_timer
```

Эта структура задается в:

- `components/app/CMakeLists.txt`
- `components/i2c_bus/CMakeLists.txt`
- `components/mpu9250/CMakeLists.txt`
- `main/CMakeLists.txt`

См. [[05-config/CMake overview]].

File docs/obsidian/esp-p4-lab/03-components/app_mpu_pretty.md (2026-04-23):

# app_mpu_pretty

Файл: `components/app/src/app_mpu_pretty.c`.

Назначение:

- обнаружить MPU;
- вывести WHO_AM_I;
- прочитать конфиги gyro/accel scale;
- периодически читать 14 байт raw telemetry;
- перевести raw accelerometer в `g`;
- перевести raw gyroscope в `dps`;
- перевести raw temperature в Celsius;
- напечатать красивую строку и JSON-подобную телеметрию.

Главное состояние:

- `s_mpu.addr`
- `s_mpu.whoami`
- `s_mpu.accel_lsb_per_g`
- `s_mpu.gyro_lsb_per_dps`
- `s_mpu.ready`

Главные функции:

- [[04-functions/app_mpu_pretty_init]]
- [[04-functions/app_mpu_pretty_log_line]]
- [[04-functions/app_mpu_i16be]]
- [[04-functions/app_mpu_accel_lsb_per_g]]
- [[04-functions/app_mpu_gyro_lsb_per_dps]]

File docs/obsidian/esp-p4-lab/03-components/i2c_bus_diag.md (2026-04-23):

# i2c_bus_diag

Файл: `components/i2c_bus/src/i2c_bus_diag.c`.

Назначение:

- помочь найти правильные пары SDA/SCL, если MPU не найден;
- попробовать набор типичных GPIO пар;
- для каждой пары создать временный I2C bus;
- проверить адреса `0x68` и `0x69`;
- удалить временный bus.

Это диагностический код. Он вызывается из `app_mpu_whoami_check()`, если обычный поиск MPU не сработал.

Главные функции:

- [[04-functions/i2c_bus_diag_sweep_mpu_pairs]]
- [[04-functions/i2c_bus_diag_probe_pair]]

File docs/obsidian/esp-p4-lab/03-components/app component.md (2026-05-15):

# app component

`components/app` — это главный прикладной компонент проекта. Именно он делает из набора отдельных модулей одну работающую прошивку.

## Что входит в компонент

Содержимое компонента:

- `src/app.c` — общий координатор;
- `src/app_wifi.c` — Wi‑Fi bringup и статусы;
- `src/app_net.c` — HTTP/WebSocket API;
- `src/app_stepper.c` — управление шаговым двигателем;
- `src/app_mpu_pretty.c` — MPU telemetry/log formatting;
- `include/*.h` — публичный интерфейс для остальных частей проекта.

С точки зрения сборки компонент объявлен в `components/app/CMakeLists.txt` и явно зависит от:

- `i2c_bus`;
- `mpu9250`;
- `esp_driver_gpio`;
- `esp_driver_uart`;
- `esp_wifi`;
- `esp_event`;
- `esp_http_server`;
- `esp_netif`;
- `nvs_flash`.

Это удобно для пояснения архитектуры: `app` — не низкоуровневый драйвер, а агрегирующий бизнес-слой прошивки.

## Главная роль компонента

У компонента три основные задачи:

1. скрыть детали ESP-IDF от `main`;
2. связать между собой сенсоры, управление двигателем и сеть;
3. дать единый жизненный цикл приложения.

Именно поэтому наружу экспортируются простые функции:

- `app_init()`;
- `app_tick()`;
- `app_tick_delay_ms()`.

## Что делает `app.c`

Файл `app.c` — центральная orchestration-точка проекта.

Он отвечает за:

- настройку уровней логирования;
- запуск I2C;
- первичный scan шины;
- проверку наличия MPU;
- запуск Wi‑Fi при включенном `CONFIG_APP_WIFI_SMOKE`;
- запуск stepper subsystem при `CONFIG_APP_MODE_L293D_TEST`;
- запуск сетевого API при `CONFIG_APP_NET_ENABLE` и готовой сети;
- периодическую генерацию system telemetry;
- вызов периодического опроса MPU.

Кроме того, `app.c` хранит два важных публичных состояния:

- `app_system_status_t` — общесистемное состояние;
- `app_i2c_status_t` — сводка по I2C и обнаружению MPU.

## Почему это хороший центр композиции

`app.c` почти не реализует аппаратную логику сам, но знает, в каком порядке запускать другие подсистемы. Это правильное разделение ответственности:

- модуль знает **как работать**;
- `app.c` знает **когда и зачем его запускать**.

Такой подход:

- уменьшает связность между модулями;
- облегчает чтение проекта;
- упрощает расширение архитектуры;
- делает объяснение на защите намного проще.

## Какие публичные данные компонент отдает другим слоям

Через `app.h` наружу доступны:

- `app_get_system_status()`;
- `app_get_i2c_status()`;
- `app_set_system_error()`.

Эти функции используются, в частности, сетевым слоем для сборки JSON-ответов.

## Важный инженерный нюанс

Компонент `app` здесь не равен одной функции или одному модулю. Это, по сути, "прикладная платформа" прошивки.

Внутри него объединены сразу три типа логики:

- orchestration;
- domain logic;
- integration с сетевыми и аппаратными подсистемами.

Для лабораторного проекта это разумный компромисс: проект остается компактным, но структура уже похожа на взрослое многомодульное приложение.

## Что особенно полезно для курсовой

На примере `components/app` удобно показать:

- принцип модульной архитектуры;
- разделение ответственности;
- единый жизненный цикл встроенного приложения;
- связь между конфигурацией и составом функциональности;
- построение API поверх внутренних статусов.

См. также:

- [[04-functions/app_init]]
- [[04-functions/app_tick]]
- [[02-architecture/System overview]]
- [[02-architecture/Runtime data flow]]

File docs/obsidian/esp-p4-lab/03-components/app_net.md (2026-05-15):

# app_net

Файл: `components/app/src/app_net.c`.

## Назначение компонента

`app_net` — сетевой фасад прошивки. Он дает внешнему клиенту доступ к состоянию системы и к управлению шаговым двигателем.

Основные задачи:

- поднять встроенный HTTP server из ESP-IDF;
- зарегистрировать REST endpoints;
- поднять WebSocket endpoint;
- собрать единый JSON состояния из нескольких подсистем;
- передать команду управления stepper через общий публичный API;
- регулярно пушить телеметрию всем WebSocket-клиентам.

## Почему этот модуль важен архитектурно

`app_net` не содержит бизнес-логики двигателя и не работает напрямую с железом. Он является transport/integration-слоем между внешним клиентом и внутренними модулями прошивки.

Это хороший признак правильной модульности: сеть отвечает за транспорт, а не за управление GPIO или вычисление фаз.

## Экспортируемые endpoints

### `GET /api/telemetry`

Возвращает единый JSON-объект, включающий:

- `system`;
- `mpu`;
- `i2c`;
- `stepper`;
- `wifi`.

Это главный endpoint для мониторинга состояния всей прошивки.

### `GET /api/wifi`

Возвращает более короткий JSON только по Wi‑Fi статусу.

### `POST /api/command`

Принимает команду для stepper. В текущей реализации команда извлекается очень просто:

- либо из JSON-поля `"command"`;
- либо как первый небесполезный символ в body.

Пример полезной нагрузки:

```json
{"command":"f"}
```

или даже просто:

```text
f
```

### `GET /ws`

WebSocket endpoint:

- принимает команды от клиента;
- после приема сразу отдает актуальный JSON-снимок;
- дополнительно получает периодические push-обновления из `app_net_tick()`.

### `OPTIONS /*`

Нужен для CORS preflight. Это особенно важно, если фронтенд запускается не с того же origin.

## Как формируется JSON

Функция `app_net_build_json()` собирает данные не из внутренних статических переменных других модулей, а через их публичные API:

- `app_stepper_get_snapshot()`;
- `app_wifi_get_status()`;
- `app_get_system_status()`;
- `app_mpu_get_status()`;
- `app_get_i2c_status()`.

Такой подход дает сразу несколько плюсов:

- модульность;
- меньшую связность;
- простую сериализацию;
- понятный контракт между подсистемами.

## Формат данных

JSON собирается вручную через `snprintf`. Это просто и прозрачно для небольшого проекта, но важно помнить ограничения:

- нужен контроль размеров буферов;
- нет автоматического escaping сложных строк;
- при росте схемы ответов код станет менее удобным.

Для текущего лабораторного масштаба это приемлемый компромисс.

## Команды управления двигателем

Сетевой слой не знает ничего про фазы L293D. Он оперирует только символом команды:

- `f` — вперед;
- `r` — назад;
- `s` — стоп;
- `w` — sweep;
- `1`, `2` — одиночные шаги;
- `a`, `b`, `c`, `d` — фиксация фазы;
- `+`, `-` — изменение скорости;
- `z` — release coils.

После извлечения символа вызывается `app_stepper_command_char(cmd)`.

## Работа WebSocket push-модели

Раз в секунду `app_net_tick()`:

1. проверяет, что сервер уже запущен;
2. ограничивает частоту отправки через `s_last_push_ms`;
3. получает список клиентских сокетов;
4. фильтрует только WebSocket-клиентов;
5. ставит асинхронную отправку через `httpd_queue_work()`.

Отдельная асинхронная функция `app_net_ws_send_work()` нужна, чтобы не отправлять frame прямо из случайного контекста.

## Внутреннее состояние

- `s_server` — handle HTTP server;
- `s_last_push_ms` — timestamp последней рассылки;
- `app_net_ws_msg_t` — временная структура для queued WS-передачи.

## CORS и интеграция с фронтендом

Функция `app_net_set_cors()` всегда выставляет заголовки:

- `Access-Control-Allow-Origin: *`
- `Access-Control-Allow-Methods: GET,POST,OPTIONS`
- `Access-Control-Allow-Headers: Content-Type`

Это значит, что API изначально подготовлен для взаимодействия с внешним web-клиентом без жесткой same-origin привязки.

## Сильные стороны реализации

- компактный API;
- единый JSON состояния;
- WebSocket push для живого интерфейса;
- отсутствие дублирования логики stepper;
- CORS уже учтен;
- использование публичных snapshot/status API вместо прямого доступа к чужому состоянию.

## Ограничения текущего решения

- JSON строится вручную;
- нет аутентификации;
- нет маршрутизации статических файлов UI в этом модуле;
- нет сложной схемы команд или подтверждений выполнения;
- нет отдельного слоя versioning для API.

Для лабораторного проекта это нормально: модуль уже демонстрирует практическую сетевую интеграцию, но не перегружен enterprise-логикой.

Главные функции:

- [[04-functions/app_net_start]]
- [[04-functions/app_net_tick]]
- [[04-functions/app_net_build_json]]
- [[04-functions/app_net_command_handler]]
- [[04-functions/app_net_ws_handler]]

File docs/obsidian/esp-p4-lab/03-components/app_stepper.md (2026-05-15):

# app_stepper

Файл: `components/app/src/app_stepper.c`.

## Назначение компонента

`app_stepper` реализует управление шаговым двигателем через драйвер `L293D`. Это один из центральных модулей проекта, потому что именно он связывает физическое исполнительное устройство с двумя каналами управления:

- локальным через `UART0`;
- удаленным через `HTTP/WebSocket`.

## Что делает модуль

Основные обязанности:

- настроить GPIO, подключенные к `L293D`;
- при необходимости настроить activity LED;
- инициализировать UART для приема символьных команд;
- хранить внутреннее состояние двигателя;
- реализовать несколько режимов движения;
- управлять фазами обмоток;
- публиковать состояние наружу;
- выдавать текстовую и машинно-читаемую телеметрию.

## Внутренние структуры

### `app_stepper_phase_t`

Описывает одну фазу возбуждения:

- уровни `in1..in4`;
- человекочитаемую метку.

Массив `s_phases` содержит 4 фазы:

- phase A;
- phase B;
- phase C;
- phase D.

Это компактная таблица управления, через которую строятся forward/reverse шаги.

### `app_stepper_state_t`

Хранит текущее runtime-состояние:

- текущий режим;
- состояние sweep-машины;
- индекс фазы;
- задержку между шагами;
- время последнего шага;
- счетчики шагов;
- готовность UART;
- состояние катушек;
- состояние светодиода;
- последнюю команду.

## Режимы работы

Поддерживаются режимы:

- `stop` — двигатель остановлен, обмотки освобождены;
- `forward` — непрерывное движение вперед;
- `reverse` — непрерывное движение назад;
- `sweep` — качание вперед-назад с паузами на краях.

Режим `sweep` особенно удобен для лабораторной демонстрации: система сразу показывает, что двигатель жив, а логика периодического tick работает.

## Символьный интерфейс команд

Модуль принимает компактные однобайтные команды.

Основные команды:

- `h` — вывести справку;
- `p` — вывести статус;
- `s` — стоп;
- `f` — движение вперед;
- `r` — движение назад;
- `w` — режим sweep;
- `1` — один шаг вперед;
- `2` — один шаг назад;
- `a`, `b`, `c`, `d` — удержание конкретной фазы;
- `+` или `=` — ускорение;
- `-` или `_` — замедление;
- `z` — release coils.

Это очень удобный интерфейс и для UART-консоли, и для простого web-клиента.

## Защита от дребезга команд

В коде есть `APP_STEPPER_DUPLICATE_CMD_GUARD_MS = 150 ms`.

Если одна и та же команда приходит слишком быстро повторно, она игнорируется. Это снижает вероятность лишних переключений режима из-за повторной отправки символов или нестабильного клиента.

## Как выполняется физический шаг

Для шага вперед:

- берется текущая фаза из `s_phases[s_stepper.phase_index]`;
- вызывается `app_stepper_apply_phase()`;
- индекс фазы циклически увеличивается.

Для шага назад:

- индекс предварительно уменьшается по кругу;
- затем активируется соответствующая фаза.

В обоих случаях увеличивается `total_steps`.

## Роль `tick`

`app_stepper_tick()` — сердце модуля. В каждом цикле она:

- читает UART, если он готов;
- раз в секунду отправляет heartbeat-telemetry;
- в зависимости от текущего режима решает, пора ли делать следующий шаг;
- обслуживает паузы на краях режима sweep.

Это не потоковая блокирующая логика, а кооперативная state machine. Такой подход хорошо согласуется с общим циклом `app_tick()`.

## Инициализация

`app_stepper_init()` выполняет:

1. настройку GPIO;
2. настройку LED, если он включен конфигом;
3. release катушек в безопасное состояние;
4. настройку UART;
5. вывод параметров в лог;
6. печать списка команд;
7. автоматический переход в режим `sweep`.

То есть после старта двигатель уже может показать демонстрационное поведение без дополнительных внешних команд.

## Публичный API

Сетевой слой использует два ключевых вызова:

- `app_stepper_command_char(char cmd)` — передать символ команды;
- `app_stepper_get_snapshot(app_stepper_snapshot_t *snapshot)` — получить снимок состояния.

Это хорошее проектное решение, потому что:

- HTTP/WebSocket не зависят от внутренней реализации state machine;
- можно менять транспорт, не меняя моторную логику;
- состояние двигателя легко сериализовать в JSON.

## Телеметрия

Модуль генерирует `@telemetry`-строки с полями:

- `mode`;
- `sweep_state`;
- `step_delay_ms`;
- `steps_per_second`;
- `phase_index`;
- `total_steps`;
- `coils_enabled`;
- `sweep_steps`;
- `uart_ready`;
- `last_command`;
- GPIO-пины.

Это делает модуль не "черным ящиком", а наблюдаемой системой.

## Ограничения и инженерные компромиссы

- используется простой фазовый шаблон из 4 состояний;
- нет профилей ускорения/торможения;
- нет контроля реального положения ротора по энкодеру;
- используется один общий tick-loop, а не отдельная RTOS-задача двигателя;
- команды односимвольные, что просто, но ограничивает расширяемость протокола.

Для учебной лабораторной прошивки это хороший баланс между простотой и наглядностью.

Главные функции:

- [[04-functions/app_stepper_init]]
- [[04-functions/app_stepper_tick]]
- [[04-functions/app_stepper_handle_command]]
- [[04-functions/app_stepper_command_char]]
- [[04-functions/app_stepper_get_snapshot]]
- [[04-functions/app_stepper_apply_phase]]
- [[04-functions/app_stepper_release]]

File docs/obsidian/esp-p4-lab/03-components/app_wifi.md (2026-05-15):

# app_wifi

Файл: `components/app/src/app_wifi.c`.

## Назначение компонента

`app_wifi` поднимает сетевую подсистему и хранит компактное состояние Wi‑Fi, которое потом используют другие части прошивки.

Основные задачи файла:

- инициализировать `NVS`;
- инициализировать `esp_netif` и default event loop;
- создать интерфейсы `STA` и `AP`;
- запустить Wi‑Fi stack;
- поднять SoftAP;
- при включенном `CONFIG_APP_WIFI_CONNECT` настроить подключение к внешней сети;
- обновлять статус подключения;
- отдавать снимок состояния наружу через `app_wifi_get_status()`.

## Что реально делает текущая реализация

Важно отделять реальный код от запланированного поведения.

### Реально выполняется сейчас

- запускается SoftAP;
- выбирается `WIFI_MODE_AP` или `WIFI_MODE_APSTA` в зависимости от `CONFIG_APP_WIFI_CONNECT` и наличия SSID;
- назначается SSID точки доступа из `CONFIG_APP_WIFI_AP_SSID_PREFIX`;
- при включенном STA-режиме задаются учетные данные для подключения к внешней сети;
- регистрируются обработчики событий Wi‑Fi и IP;
- обновляются поля `ap_started`, `sta_attempted`, `sta_connected`, `ap_ip`, `sta_ip`.

### Что в коде есть, но сейчас фактически не используется

- функция `app_wifi_log_scan_results()` реализована, но не вызывается;
- функция `app_wifi_build_ap_ssid()` умеет строить SSID с MAC-суффиксом, однако в текущем коде вызывается как `app_wifi_build_ap_ssid(..., NULL)`, поэтому в реальности используется просто строка-префикс без MAC-суффикса.

Это стоит прямо фиксировать, чтобы документация не расходилась с проектом.

## Внутреннее состояние

Ключевые static-переменные:

- `s_sta_netif` — интерфейс станции;
- `s_ap_netif` — интерфейс точки доступа;
- `s_wifi_started` — защита от повторного запуска;
- `s_status` — структура `app_wifi_status_t`, которую видят остальные модули.

Структура `app_wifi_status_t` содержит:

- `initialized` — прошла ли базовая инициализация Wi‑Fi;
- `ap_started` — запущена ли точка доступа;
- `sta_attempted` — пыталась ли прошивка подключиться как клиент;
- `sta_connected` — подключилась ли она как клиент;
- `ap_ssid` — SSID точки доступа;
- `ap_ip` — IP точки доступа;
- `sta_ip` — IP клиента в режиме STA;
- `last_error` — последний `esp_err_t`.

## Последовательность запуска

Функция `app_wifi_smoke_run()` делает следующее:

1. Проверяет, доступен ли Wi‑Fi stack для текущей конфигурации ESP-IDF.
2. Защищается от повторного запуска через `s_wifi_started`.
3. Инициализирует `NVS`.
4. Инициализирует `esp_netif`.
5. Создает event loop.
6. Создает default netif для `STA` и `AP`.
7. Вызывает `esp_wifi_init()`.
8. Регистрирует общие обработчики событий.
9. Выбирает режим `AP` или `APSTA`.
10. Конфигурирует SoftAP.
11. При необходимости конфигурирует STA.
12. Запускает Wi‑Fi и отключает power save через `esp_wifi_set_ps(WIFI_PS_NONE)`.
13. Обновляет статус и возвращает `ESP_OK`.

## Работа событийной модели

В проекте есть два уровня обработки событий:

- `app_wifi_event_handler_common()` — общая часть;
- `app_wifi_event_handler()` — дополнительные реакции для STA-режима.

Это разделение удобно, потому что AP-события нужны всегда, а STA-логика включается условно через `CONFIG_APP_WIFI_CONNECT`.

Типовые события:

- `WIFI_EVENT_AP_START` → точка доступа поднята;
- `WIFI_EVENT_AP_STOP` → точка доступа остановлена;
- `WIFI_EVENT_STA_START` → можно инициировать подключение клиента;
- `WIFI_EVENT_STA_DISCONNECTED` → фиксируется ошибка и при необходимости выполняется retry;
- `IP_EVENT_STA_GOT_IP` → клиент успешно получил IP;
- `IP_EVENT_AP_STAIPASSIGNED` → обновляется IP-информация AP.

## Как компонент используется остальной системой

- `app.c` вызывает `app_wifi_smoke_run()` при старте;
- `app_net.c` читает `app_wifi_get_status()` при формировании JSON;
- логика запуска API зависит от результата инициализации Wi‑Fi.

То есть `app_wifi` — не просто драйвер, а поставщик сетевого статуса для других модулей.

## Ограничения и особенности

- SoftAP — основной режим работы текущей конфигурации;
- scan AP уже реализован, но не встроен в runtime-цепочку;
- имя точки доступа пока не уникализируется через MAC, хотя функция для этого заготовлена;
- код написан как bringup/smoke-уровень, а не как полнофункциональный network manager.

## Что можно использовать в курсовой

На этом модуле удобно показать:

- инициализацию сетевой подсистемы ESP-IDF;
- использование event-driven модели;
- построение собственного слоя статуса над SDK;
- различие между режимами `AP`, `STA` и `APSTA`;
- роль `Kconfig` в управлении составом функциональности.

Главные функции:

- [[04-functions/app_wifi_smoke_run]]
- [[04-functions/app_wifi_get_status]]
- [[04-functions/app_wifi_event_handler_common]]
- [[04-functions/app_wifi_build_ap_ssid]]
- [[04-functions/app_wifi_nvs_init_once]]

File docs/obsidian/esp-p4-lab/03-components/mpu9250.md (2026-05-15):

# mpu9250

Файл: `components/mpu9250/src/mpu9250.c`.

## Назначение компонента

`mpu9250` — это компактный вспомогательный модуль для базовой работы с датчиком семейства MPU. Его задача — не заменить полноценный драйвер, а закрыть минимально необходимый функционал для проекта:

- найти устройство на шине;
- прочитать `WHO_AM_I`;
- интерпретировать код устройства в человекочитаемое имя.

## Почему модуль выделен отдельно

Хотя функций здесь немного, вынесение в отдельный компонент полезно:

- логика поиска датчика отделена от I2C-слоя;
- `app_mpu_pretty.c` не обязан знать детали начального probe;
- проект получает чистую прослойку "sensor discovery".

## Что делает каждая функция

### `mpu9250_probe_addr()`

Последовательно проверяет адреса:

- `0x68`;
- `0x69`.

Если устройство отвечает, адрес возвращается через `out_addr`.

Это соответствует типовой схеме MPU, где младший бит адреса может зависеть от состояния `AD0`.

### `mpu9250_read_whoami()`

Перед чтением `WHO_AM_I` выполняется запись `0x00` в `PWR_MGMT_1`, то есть датчик пробуждается из sleep-состояния. После этого читается регистр `0x75`.

Это очень практичный шаг: модуль сразу учитывает типовую особенность MPU, а не перекладывает ее на вызывающий код.

### `mpu9250_probe_and_read_whoami()`

Комбинированная функция:

1. найти адрес;
2. прочитать `WHO_AM_I`.

Именно этот вызов чаще всего используется прикладным слоем.

### `mpu9250_whoami_name()`

Возвращает строковое описание модели:

- `0x70` → `MPU-6500`;
- `0x71` → `MPU-9250`;
- `0x73` → `MPU-9255/variant`;
- иначе → `unknown/clone`.

Это полезно для логов и для телеметрии, особенно если на стенде встречаются совместимые модули или клоны.

## Что модуль сознательно НЕ делает

Он не умеет:

- настраивать DLPF;
- задавать частоты выборки;
- включать/отключать оси;
- читать fifo;
- работать с магнитометром;
- выполнять калибровку.

То есть это именно helper-слой для обнаружения и базовой идентификации датчика.

## Связь с другими компонентами

- использует `i2c_bus` как транспорт;
- вызывается из `app.c` для первичной проверки наличия MPU;
- вызывается из `app_mpu_pretty_init()` для ленивой инициализации telemetry-слоя.

## Почему это полезно для курсовой

На этом модуле удобно показать идею минимального driver-like abstraction:

- низкий слой (`i2c_bus`) умеет только транспорт;
- слой `mpu9250` знает про конкретный девайс и его идентификатор;
- верхний слой `app_mpu_pretty` уже строит телеметрию и форматирование.

Это хороший пример многоуровневой декомпозиции даже в небольшом embedded-проекте.

Главные функции:

- [[04-functions/mpu9250_probe_addr]]
- [[04-functions/mpu9250_read_whoami]]
- [[04-functions/mpu9250_probe_and_read_whoami]]
- [[04-functions/mpu9250_whoami_name]]

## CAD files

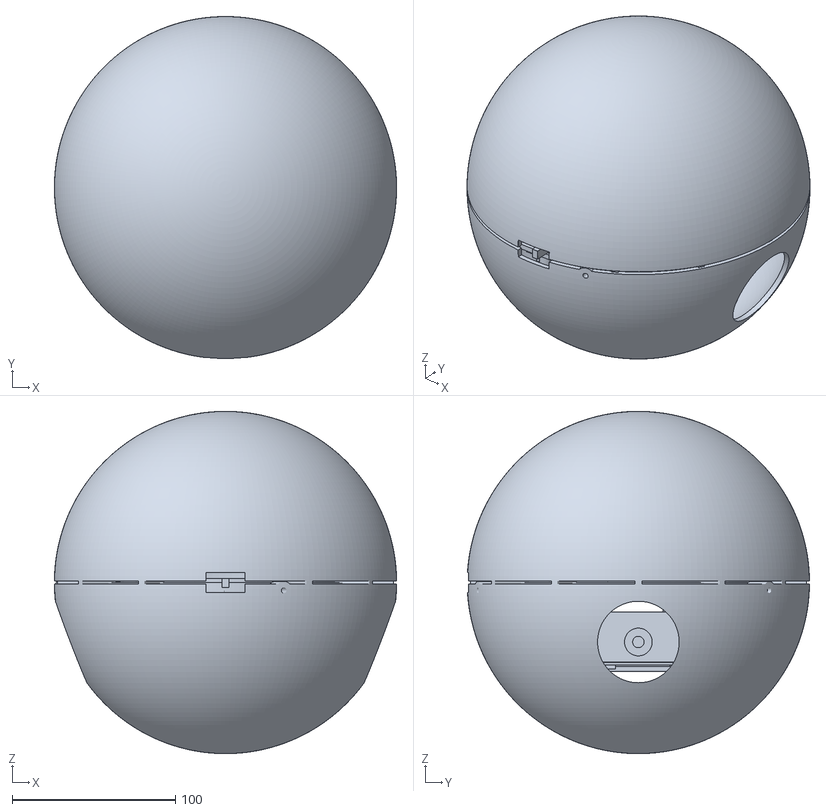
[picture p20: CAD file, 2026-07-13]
3D-model/fiish.stl
210.0 x 209.8 x 210.0

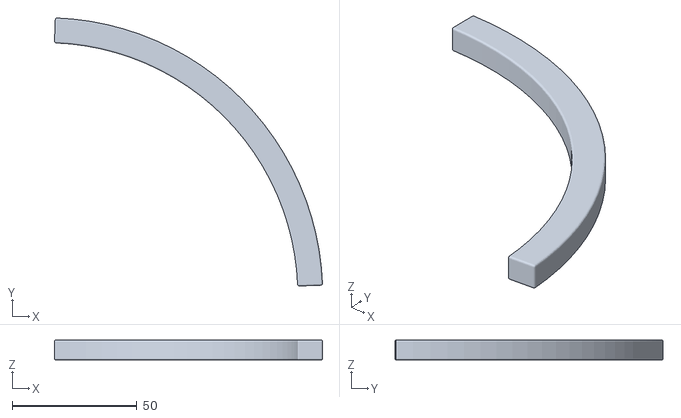
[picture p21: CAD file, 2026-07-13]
mechanical/spherical_robot/exports/stl/FIXED_FRAME_RING_QUADRANT_01.stl
107.3 x 107.3 x 8.00

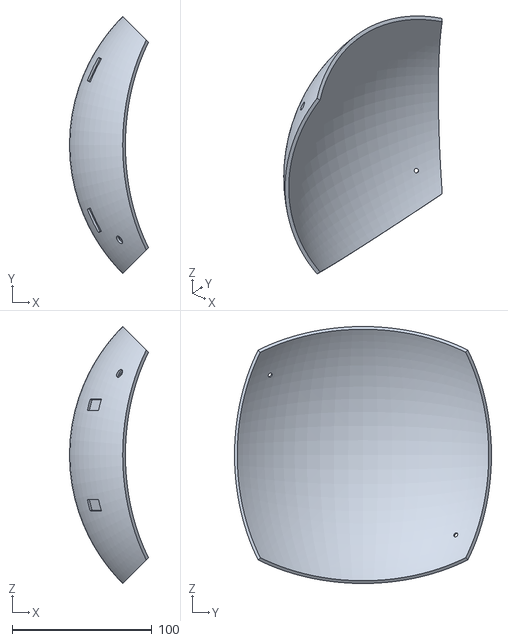
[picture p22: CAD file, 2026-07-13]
mechanical/spherical_robot/exports/stl/SHELL_SEGMENT_02_NEG_X.stl
56.6 x 183.8 x 183.8

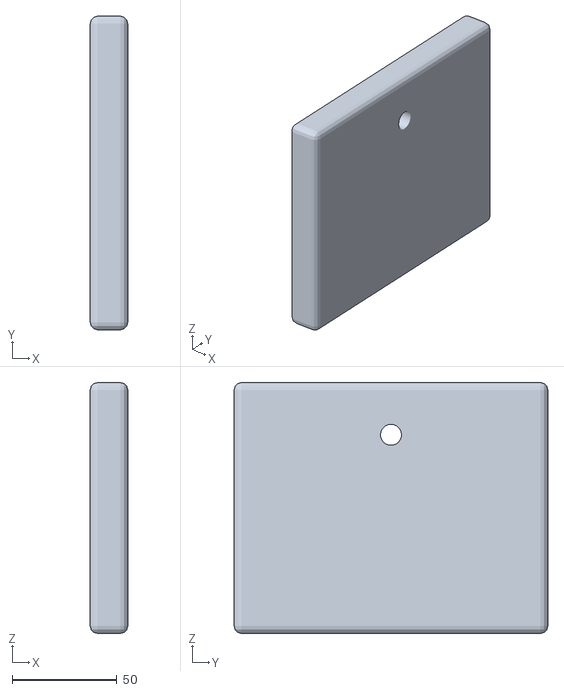
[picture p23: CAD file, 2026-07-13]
mechanical/spherical_robot/exports/stl/BALANCE_STAND_SIDE.stl
18.0 x 150.0 x 120.0

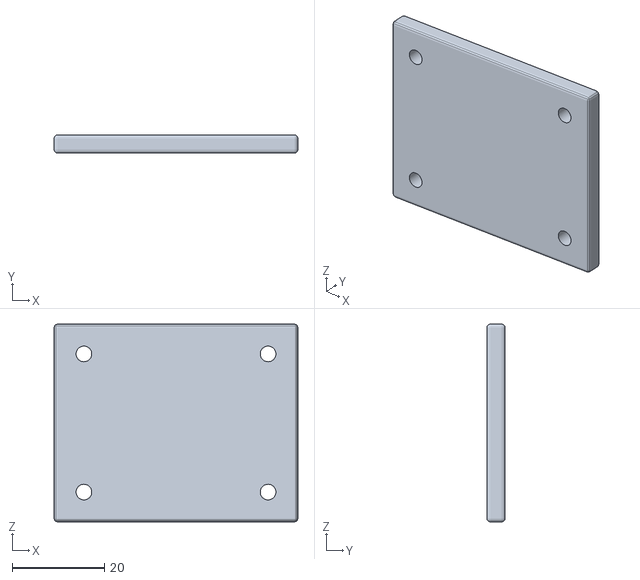
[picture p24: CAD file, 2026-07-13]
mechanical/spherical_robot/exports/stl/DRIVER_TRAY.stl
53.0 x 4.00 x 43.0

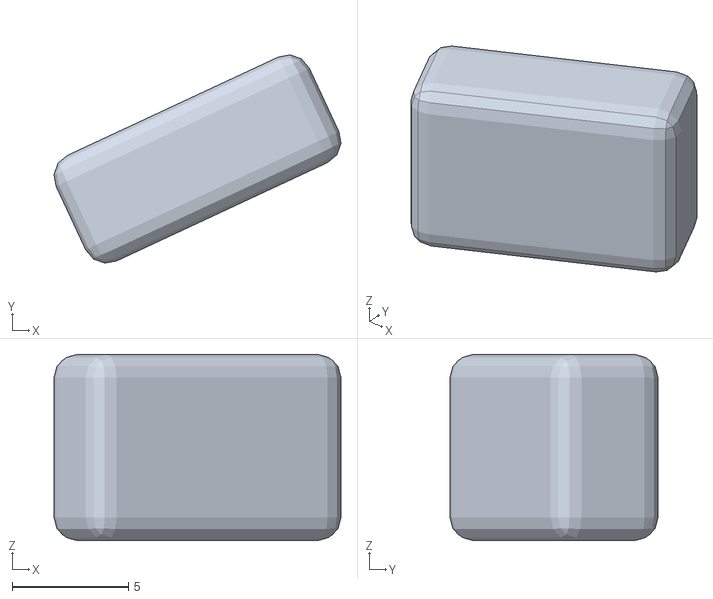
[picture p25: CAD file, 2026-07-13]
mechanical/spherical_robot/exports/stl/CABLE_CLIP_01.stl
12.3 x 8.94 x 8.00

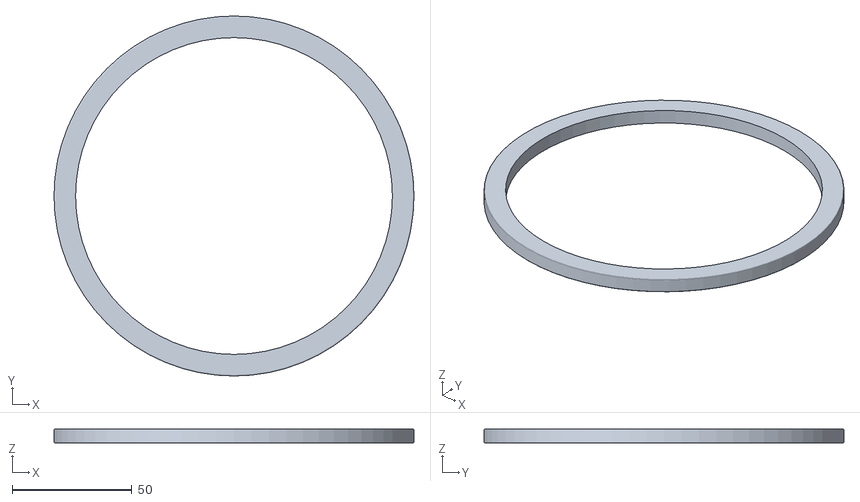
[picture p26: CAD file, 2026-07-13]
mechanical/spherical_robot/exports/stl/FIXED_FRAME_TOP.stl
150.0 x 150.0 x 6.00

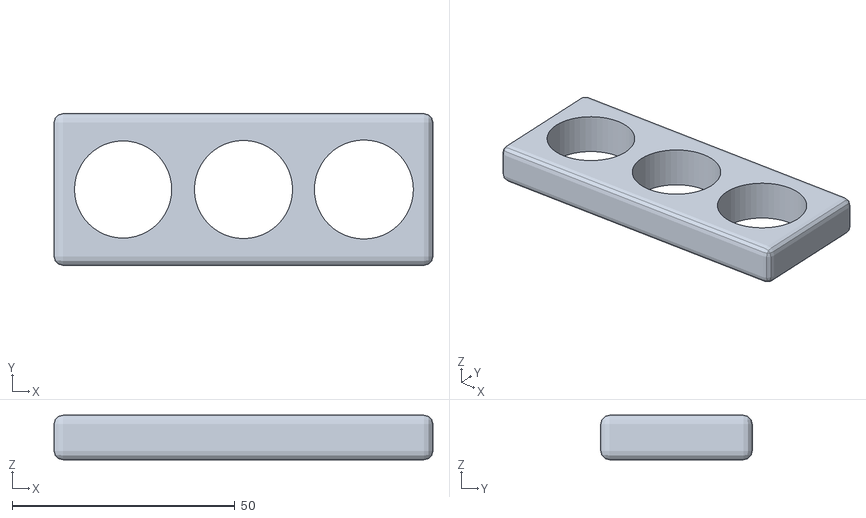
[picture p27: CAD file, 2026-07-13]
mechanical/spherical_robot/exports/stl/BEARING_FIT_COUPON.stl
85.0 x 34.0 x 10.0

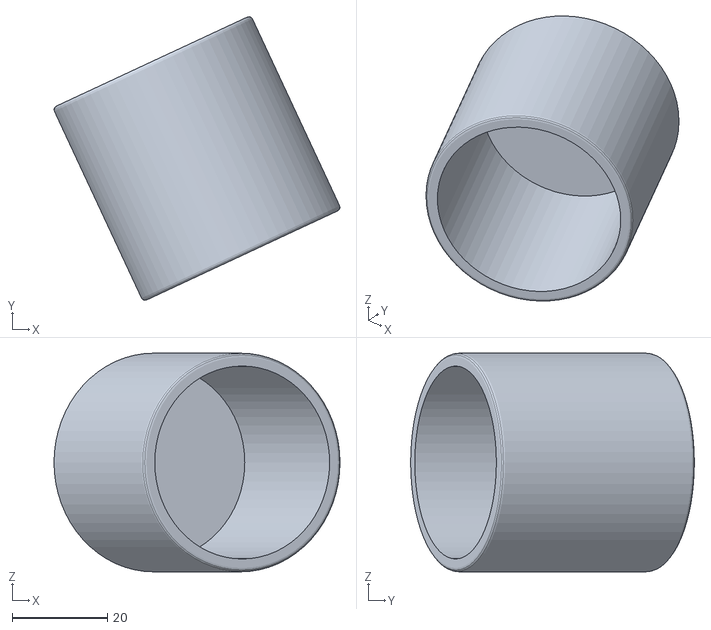
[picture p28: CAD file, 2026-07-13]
mechanical/spherical_robot/exports/stl/BALLAST_HOLDER.stl
60.2 x 59.7 x 46.0

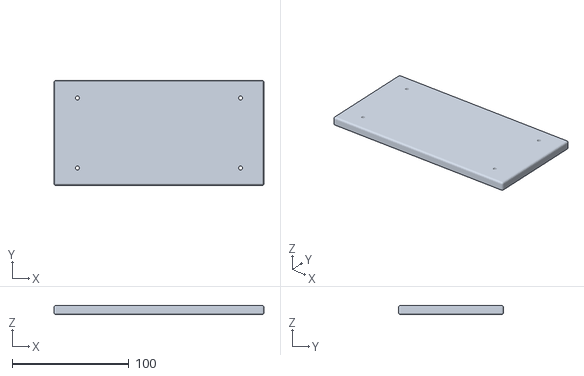
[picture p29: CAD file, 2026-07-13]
mechanical/spherical_robot/exports/stl/PENDULUM_TEST_STAND_BASE.stl
180.0 x 90.0 x 8.00

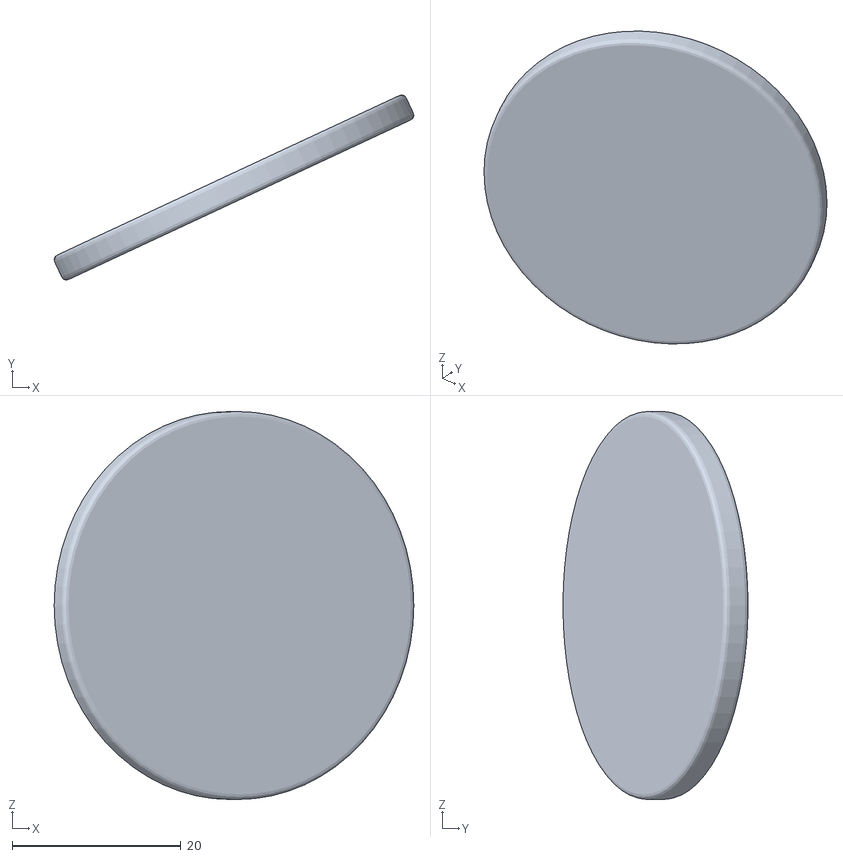
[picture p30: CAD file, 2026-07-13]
mechanical/spherical_robot/exports/stl/BALLAST_LID.stl
42.6 x 21.9 x 46.0

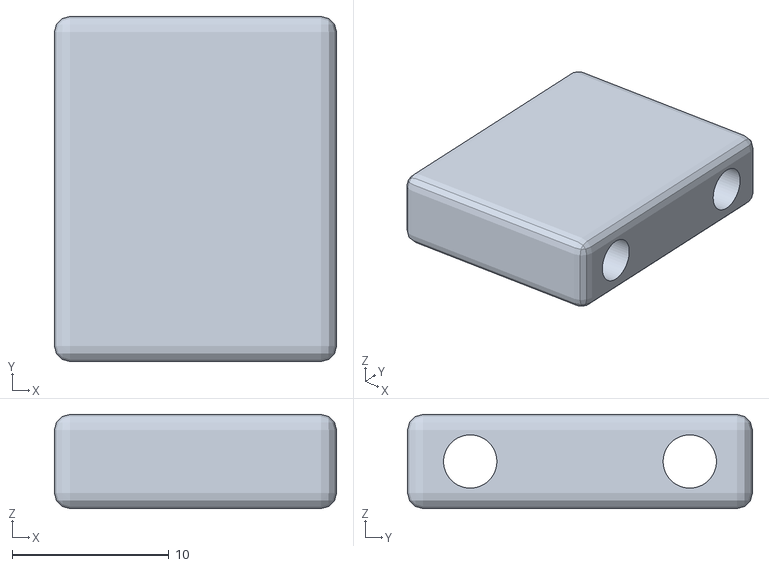
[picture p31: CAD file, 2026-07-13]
mechanical/spherical_robot/exports/stl/CHARGE_PORT_HOLDER.stl
18.0 x 22.0 x 6.00

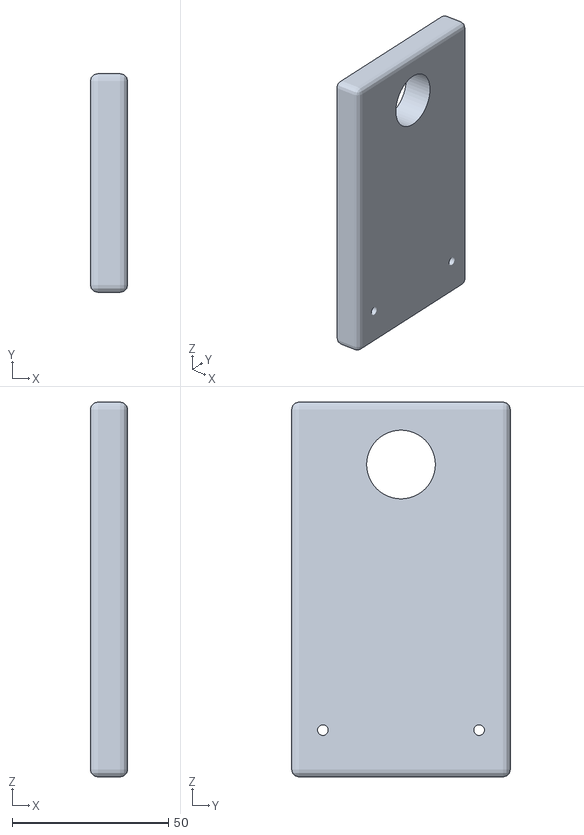
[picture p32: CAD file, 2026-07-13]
mechanical/spherical_robot/exports/stl/PENDULUM_TEST_STAND_UPRIGHT.stl
12.0 x 70.0 x 120.0

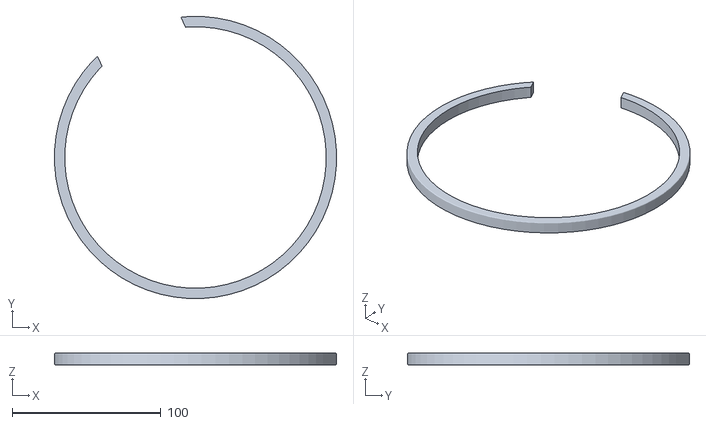
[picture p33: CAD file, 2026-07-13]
mechanical/spherical_robot/exports/stl/STEERING_RING.stl
189.8 x 189.8 x 8.00

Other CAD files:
mechanical/spherical_robot/exports/stl/SHELL_SEGMENT_04_NEG_Y.stl
mechanical/spherical_robot/exports/stl/SHELL_SEGMENT_03_POS_Y.stl
mechanical/spherical_robot/exports/stl/M3_TEST_COUPON.stl
mechanical/spherical_robot/exports/stl/SWITCH_HOLDER.stl
3D-model/fiish.blend
mechanical/spherical_robot/blender/spherical_robot.blend
mechanical/spherical_robot/exports/stl/BALL_STAND.stl
mechanical/spherical_robot/exports/stl/BATTERY_TRAY.stl
mechanical/spherical_robot/exports/stl/ENCODER_GUARD.stl
mechanical/spherical_robot/exports/stl/EQUATOR_EDGE_CLIP_01.stl
mechanical/spherical_robot/exports/stl/FIXED_FRAME_BOTTOM.stl
mechanical/spherical_robot/exports/stl/FRAME_STRUT_TOP_01.stl
mechanical/spherical_robot/exports/stl/HEAT_INSERT_TEMPLATE.stl
mechanical/spherical_robot/exports/stl/IMU_MOUNT.stl
mechanical/spherical_robot/exports/stl/MOTOR_CLAMP.stl
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

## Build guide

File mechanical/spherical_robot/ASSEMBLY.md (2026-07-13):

# Сборка P0.1

1. Напечатать coupons, измерить купленные компоненты и обновить параметры `_PLACEHOLDER`. Перестроить модель командой Blender из каталога репозитория.
2. Установить два подшипника в `SHAFT_SUPPORT_LEFT/RIGHT` только после успешного bearing coupon. Собрать supports, `MOTOR_MOUNT`, `MOTOR_CLAMP` и `STEERING_RING`; мотор должен сниматься без демонтажа батареи или PCB.
3. Вставить стальной вал через обе опоры. Выходной вал редуктора соединить со стальным валом coupling-элементом; нагрузка маятника воспринимается двумя подшипниками, не валом редуктора.
4. Закрепить `PENDULUM_ARM` на валу механическим clamp/винтом. Выбрать радиус балласта 52/60/68 мм. Установить только один проверенный стальной пакет 200/300/400 г в `BALLAST_HOLDER`, закрыть `BALLAST_LID` винтами.
5. Установить magnet/rotor энкодера на вал и неподвижный sensor на steering frame. Проверить, что ни один провод не входит в вращающийся узел.
6. На pendulum test stand вручную и от ограниченного источника выполнить оборот 0–360°; проверить encoder, биение вала, нагрев и удержание балласта.
7. Собрать четыре quadrant fixed ring, верхнее/нижнее кольца и восемь struts. Установить steering frame, рулевой привод и mechanical stops ±65°. Кабели вести только по внешней стороне fixed frame через `CABLE_CLIP_*`.
8. Установить PCB tray, battery tray, driver tray и вертикальный IMU mount. Батарея фиксируется ремнём и извлекается через люк 92×58 мм; PCB заменяется после снятия одной shell panel.
9. Вне оболочки прогнать анимационные крайние положения: yaw −65/0/+65° и pendulum 0/90/180/270/360°. Номинальный отчёт сцены: `PASS`, минимум 4.0 мм. После изменения любого measured envelope проверку повторить.
10. Вставить M3 heat inserts в edge clips по шаблону. Собрать шесть shell panels вокруг готового механизма, используя alignment keys; утопленные головки M3 не должны выходить за теоретическую сферу.
11. Установить service hatch, зарядный разъём и выключатель. Проверить доступ к винтам, замену батареи через люк, замену мотора через снятую side panel, замену PCB/подшипников после локальной разборки.
12. На ball stand проверить статический баланс с лёгким макетом балласта, затем на balance stand определить реальный COM. Первый rolling test выполнять с ограничением тока и мягкими упорами вокруг зоны испытаний.

Разборка выполняется в обратном порядке. Не пытаться вынуть вал до снятия ballast holder и encoder rotor. Не заряжать аккумулятор внутри закрытого шара до проверки BMS, температуры и доступности аварийного выключателя.

## Воспроизводимость

```bash
blender --background --factory-startup --python mechanical/spherical_robot/blender/build_robot.py
python mechanical/spherical_robot/calculations.py
```

Первый вызов заново строит сцену, проверяет collision/manifold, сохраняет `spherical_robot.blend`, экспортирует STL/GLB и обязательные рендеры.

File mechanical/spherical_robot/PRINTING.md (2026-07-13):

# Печать P0.1

Принтер: Anycubic Kobra 2 Pro, рабочее поле 220×220×250 мм. Единицы STL — миллиметры. Машиночитаемая таблица по каждому файлу: `exports/print_manifest.json`; ниже — компактная инструкция для всех экспортов.

Общие правила: сопло 0.4 мм, слой 0.20 мм; minimum local wall 1.2 мм; shell 2.8 мм; structural wall ≥2.4 мм. Сначала напечатать `M3_TEST_COUPON`, `BEARING_FIT_COUPON`, `HEAT_INSERT_TEMPLATE` и `SPHERICAL_JOINT_TEST_FRAGMENT`. Не масштабировать посадочные детали в slicer.

| STL-файл(ы) | Материал | Ориентация | Стенки | Infill | Supports | Brim | Кол-во |
|---|---|---|---:|---:|---|---|---:|
| `SHELL_SEGMENT_01_POS_X` … `06_NEG_Z` | PETG; PLA для первого fit | rim на стол, внешняя поверхность вверх | 5 | 18% gyroid | нет | да, 5 мм | по 1 |
| `SERVICE_HATCH` | PETG/PLA | внутренней плоскостью на стол | 5 | 30% | нет | нет | 1 |
| `EQUATOR_EDGE_CLIP_01` | PETG | плоским боком | 6 | 60% | нет | нет | 12 |
| `SEGMENT_ALIGNMENT_KEY` | PETG | наибольшей плоскостью | 5 | 80% | нет | нет | 12 |
| `TPU_GRIP_01_POS_X` | TPU 95A | внешней плоскостью на стол | 3 | 100% | нет | нет | 24 |
| `FIXED_FRAME_RING_QUADRANT_01` | PETG | плоско | 6 | 45% | нет | нет | 4 |
| `FIXED_FRAME_TOP`, `FIXED_FRAME_BOTTOM` | PETG | плоско | 6 | 45% | нет | нет | по 1 |
| `FRAME_STRUT_TOP_01` | PETG | горизонтально, ось параллельно столу | 6 | 45% | нет | да | 8 |
| `STEERING_RING` | PETG | плоско | 7 | 45% | нет | да, 5 мм | 1 |
| `SHAFT_SUPPORT_LEFT`, `SHAFT_SUPPORT_RIGHT` | PETG | широкой боковой плоскостью | 7 | 55% | нет | нет | по 1 |
| `MOTOR_MOUNT` | PETG | основанием на стол | 6 | 45% | нет | нет | 1 |
| `MOTOR_CLAMP` | PETG | широкой плоскостью | 6 | 50% | нет | нет | 1 |
| `STEERING_ACTUATOR_MOUNT` | PETG | основанием на стол | 6 | 45% | нет | нет | 1 |
| `ENCODER_GUARD` | PETG | открытой стороной вверх | 5 | 35% | нет | нет | 1 |
| `PENDULUM_ENCODER_GUARD` | PETG | широкой плоскостью | 5 | 40% | нет | нет | 1 |
| `PENDULUM_ARM` | PETG | широкой боковой плоскостью | 8 | 70% | нет | да | 1 |
| `BALLAST_HOLDER` | PETG | закрытым торцом на стол | 7 | 50% | нет | нет | 1 |
| `BALLAST_LID` | PETG | плоско | 5 | 60% | нет | нет | 1 |
| `PCB_TRAY` | PETG | плоско | 5 | 35% | нет | нет | 1 |
| `BATTERY_TRAY` | PETG | основанием на стол | 6 | 40% | нет | нет | 1 |
| `IMU_MOUNT` | PETG | широкой плоскостью | 5 | 50% | нет | нет | 1 |
| `DRIVER_TRAY` | PETG | широкой плоскостью | 5 | 35% | нет | нет | 1 |
| `SWITCH_HOLDER`, `CHARGE_PORT_HOLDER` | PETG | плоско | 5 | 45% | нет | нет | по 1 |
| `CABLE_CLIP_01` | PETG | плоско | 4 | 60% | нет | нет | 8 |
| `BALL_STAND` | PETG/PLA | плоско | 5 | 25% | нет | да | 1 |
| `BALANCE_STAND_SIDE` | PETG/PLA | широкой плоскостью | 6 | 25% | нет | да | 2 |
| `PENDULUM_TEST_STAND_BASE` | PETG/PLA | плоско | 5 | 25% | нет | нет | 1 |
| `PENDULUM_TEST_STAND_UPRIGHT` | PETG/PLA | широкой плоскостью | 6 | 40% | нет | да | 2 |
| `SEGMENT_ALIGNMENT_TEMPLATE` | PETG/PLA | плоско | 5 | 35% | нет | нет | 1 |
| `M3_TEST_COUPON`, `BEARING_FIT_COUPON`, `HEAT_INSERT_TEMPLATE` | материал будущей детали | плоско | 5–6 | 80% | нет | нет | по 1 |
| `SPHERICAL_JOINT_TEST_FRAGMENT` | материал оболочки | торцом дуги на стол | 5 | 25% | нет | да при необходимости | 1 |

Крупнейшая shell panel после re-import: 183.85×183.85×56.56 мм. С brim 5 мм и краевым запасом 8 мм расчётный footprint ≈209.85 мм. Steering ring Ø190 мм с теми же ограничениями занимает 216 мм; размещать строго по центру стола.

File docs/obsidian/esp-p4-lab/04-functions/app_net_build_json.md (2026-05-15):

# app_net_build_json

Исходник: `components/app/src/app_net.c`.

`app_net_build_json()` собирает общий telemetry JSON.

## Почему эта функция одна из самых важных в проекте

Это центральная функция сетевой сериализации состояния. Через нее почти весь внутренний runtime проекта превращается в единый JSON-документ для HTTP и WebSocket.

Источник данных:

- `app_stepper_get_snapshot(&stepper)`;
- `app_wifi_get_status(&wifi)`.

Но это только часть картины. В текущем коде функция также читает:

- `app_get_system_status(&system)`;
- `app_mpu_get_status(&mpu)`;
- `app_get_i2c_status(&i2c)`.

JSON содержит:

- `ok`;
- `telemetry.system.*`;
- `telemetry.mpu.*`;
- `telemetry.i2c.*`;
- `telemetry.stepper.mode`;
- `telemetry.stepper.sweepState`;
- `telemetry.stepper.delayMs`;
- `telemetry.stepper.stepsPerSecond`;
- `telemetry.stepper.phaseIndex`;
- `telemetry.stepper.totalSteps`;
- `telemetry.stepper.coilsEnabled`;
- `telemetry.stepper.sweepSteps`;
- `telemetry.stepper.uartReady`;
- `telemetry.stepper.lastCommand`;
- `telemetry.stepper.pins`;
- `telemetry.stepper.ledGpio`;
- `telemetry.wifi.initialized`;
- `telemetry.wifi.apStarted`;
- `telemetry.wifi.staAttempted`;
- `telemetry.wifi.staConnected`;
- `telemetry.wifi.apSsid`;
- `telemetry.wifi.apIp`;
- `telemetry.wifi.staIp`;
- `telemetry.wifi.lastError`.

## Как функция обрабатывает строки и optional-поля

Внутри используется helper `app_net_json_str()`, который:

- возвращает `null`, если строка пустая или отсутствует;
- иначе оборачивает строку в JSON-кавычки.

Это важно для полей вроде:

- ошибок;
- адреса MPU;
- `whoAmI`;
- `model`;
- scan summary.

## Как собирается сводный статус

Функция делает несколько полезных преобразований:

- собирает список I2C-устройств в JSON-массив;
- выбирает IP Wi‑Fi с приоритетом `sta_ip`, затем `ap_ip`;
- нормализует Wi‑Fi error как `null`, если ошибки нет;
- сериализует и stepper, и sensor, и system-данные в один документ.

## Где используется

Эта функция фактически лежит под двумя внешними сценариями:

- `GET /api/telemetry`;
- WebSocket push/response.

То есть один и тот же JSON-слепок используется и для pull-модели, и для push-модели. Это удачное решение: клиент видит одинаковую схему данных независимо от транспорта.

## Ограничения реализации

- JSON строится вручную через `snprintf`;
- структура фиксирована и довольно большая;
- при сильном росте протокола такой стиль станет сложнее сопровождать.

Но для текущего стенда это одна из самых наглядных функций проекта: именно здесь видно, как отдельные подсистемы превращаются в единый внешний API.

Функция возвращает количество записанных байт с учетом защиты от переполнения буфера.

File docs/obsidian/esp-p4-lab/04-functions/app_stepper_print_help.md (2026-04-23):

# app_stepper_print_help

Исходник: `components/app/src/app_stepper.c`.

`app_stepper_print_help()` печатает список команд stepper.

Команды включают:

- help/status;
- stop/forward/reverse/sweep;
- single-step forward/reverse;
- hold phase A/B/C/D;
- speed up / slow down;
- release coils.

Это справка для UART пользователя, но команды совпадают с network API.

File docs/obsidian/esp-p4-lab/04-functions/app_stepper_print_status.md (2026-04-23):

# app_stepper_print_status

Исходник: `components/app/src/app_stepper.c`.

`app_stepper_print_status()` печатает состояние stepper.

Поля:

- mode;
- delay;
- steps/s;
- phase;
- total_steps;
- coils;
- sweep_steps;
- uart state.

После text log вызывает `app_stepper_emit_telemetry("status")`.

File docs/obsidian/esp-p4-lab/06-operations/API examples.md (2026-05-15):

# API examples

## Назначение API

Сетевой API проекта нужен для двух вещей:

- читать текущее состояние прошивки;
- передавать команды управления шаговым двигателем.

В текущем виде API достаточно прост, чтобы его можно было использовать:

- вручную через `curl`;
- из web-приложения;
- из тестового скрипта;
- как источник примеров для описания в курсовой.

Базовый адрес при работе через SoftAP:

```text
http://192.168.4.1
```

## Получить Wi‑Fi status

```bash
curl http://192.168.4.1/api/wifi
```

Типичный смысл ответа:

- инициализирован ли Wi‑Fi;
- поднят ли SoftAP;
- пытался ли модуль подключаться как STA;
- какой IP сейчас у AP/STA.

## Получить общую телеметрию

```bash
curl http://192.168.4.1/api/telemetry
```

Это главный endpoint. Он возвращает сводное состояние по разделам:

- `system`
- `mpu`
- `i2c`
- `stepper`
- `wifi`

Именно этот endpoint удобнее всего использовать как основу для будущего web-dashboard.

## Команды управления двигателем

### Остановить мотор

```bash
curl -X POST http://192.168.4.1/api/command -H 'Content-Type: application/json' -d '{"command":"s"}'
```

### Запустить вперед

```bash
curl -X POST http://192.168.4.1/api/command -H 'Content-Type: application/json' -d '{"command":"f"}'
```

### Запустить назад

```bash
curl -X POST http://192.168.4.1/api/command -H 'Content-Type: application/json' -d '{"command":"r"}'
```

### Включить режим sweep

```bash
curl -X POST http://192.168.4.1/api/command -H 'Content-Type: application/json' -d '{"command":"w"}'
```

### Один шаг вперед

```bash
curl -X POST http://192.168.4.1/api/command -H 'Content-Type: application/json' -d '{"command":"1"}'
```

### Один шаг назад

```bash
curl -X POST http://192.168.4.1/api/command -H 'Content-Type: application/json' -d '{"command":"2"}'
```

### Ускорить

```bash
curl -X POST http://192.168.4.1/api/command -H 'Content-Type: application/json' -d '{"command":"+"}'
```

### Замедлить

```bash
curl -X POST http://192.168.4.1/api/command -H 'Content-Type: application/json' -d '{"command":"-"}'
```

### Освободить катушки

```bash
curl -X POST http://192.168.4.1/api/command -H 'Content-Type: application/json' -d '{"command":"z"}'
```

## Упрощенный формат body

В текущем коде поддерживается не только JSON, но и короткое текстовое тело. Например:

```bash
curl -X POST http://192.168.4.1/api/command -d 's'
```

Это удобно для ручной проверки API и для минималистичных клиентов.

## Что возвращает `POST /api/command`

После успешного выполнения команда не просто отвечает `OK`, а возвращает актуальную телеметрию через тот же механизм, что и `GET /api/telemetry`.

Это удобно, потому что клиент сразу получает обновленное состояние системы после команды.

## WebSocket

Для постоянного соединения используется endpoint:

```text
ws://192.168.4.1/ws
```

Через него можно:

- отправлять те же команды;
- получать обновления состояния раз в секунду.

## Почему это полезно для курсовой

Этот раздел дает готовые практические примеры взаимодействия с embedded-устройством по сети. Их можно использовать:

- как примеры API-запросов;
- как основу для описания REST/WebSocket интерфейса;
- как доказательство прикладной ценности проекта.

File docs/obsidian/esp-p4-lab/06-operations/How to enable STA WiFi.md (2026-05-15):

# How to enable STA WiFi

## Текущее состояние проекта

Сейчас проект по умолчанию работает как автономная точка доступа. Подключение к внешнему роутеру в режиме STA выключено:

```text
# CONFIG_APP_WIFI_CONNECT is not set
```

Это означает, что в типовой конфигурации устройство поднимает собственный SoftAP и не пытается подключаться к существующей Wi‑Fi сети.

## Зачем включать STA-режим

STA-режим нужен, если требуется:

- включить ESP в уже существующую локальную сеть;
- обращаться к устройству не только через `192.168.4.1`, но и по IP от роутера;
- интегрировать устройство в более общий стенд;
- не переключаться вручную на SoftAP ESP каждый раз.

## Как включить STA-подключение

Открыть конфигурацию проекта:

```bash
idf.py menuconfig
```

Дальше в разделе `app`:

- включить `attempt Wi-Fi connect after scan`;
- задать `Wi-Fi SSID`;
- задать `Wi-Fi password`;
- сохранить конфигурацию;
- пересобрать проект;
- прошить устройство.

## Что изменится после этого

После включения `CONFIG_APP_WIFI_CONNECT` и задания SSID/PASSWORD функция `app_wifi_smoke_run()` начнет:

- создавать и AP, и STA интерфейсы;
- выбирать режим `WIFI_MODE_APSTA`;
- оставлять SoftAP активным;
- конфигурировать клиентское подключение к роутеру;
- при `WIFI_EVENT_STA_START` вызывать `esp_wifi_connect()`;
- при `WIFI_EVENT_STA_DISCONNECTED` выполнять retry до лимита;
- при `IP_EVENT_STA_GOT_IP` сохранять `sta_ip`.

То есть устройство сохранит автономный способ подключения через свой AP, но одновременно сможет войти в внешнюю сеть.

## Почему SoftAP при этом не пропадает

Это важная особенность архитектуры проекта. Здесь не делается переключение “или AP, или STA”. Вместо этого используется режим `APSTA`, если конфигурация это позволяет.

Преимущества такого решения:

- UART и SoftAP остаются fallback-инструментами;
- проект удобнее демонстрировать;
- снижение зависимости от внешней сети;
- проще вернуть контроль над устройством даже при проблемах с роутером.

## Что проверить после включения STA

После прошивки полезно проверить:

1. точка доступа ESP по-прежнему поднимается;
2. в `/api/wifi` поле `staAttempted` стало `true`;
3. после успешного подключения `staConnected == true`;
4. появилось ненулевое `staIp`;
5. командами API по-прежнему можно управлять устройством.

## Ограничение текущей реализации

Хотя в `app_wifi.c` есть функция `app_wifi_log_scan_results()`, она сейчас не вызывается автоматически. Поэтому включение STA не означает, что проект уже печатает полноценный список найденных сетей при загрузке. Подключение работает, но расширенная визуализация scan пока не встроена в runtime-сценарий.

См. также:

- [[03-components/app_wifi]]
- [[04-functions/app_wifi_event_handler_common]]
- [[06-operations/Runtime WiFi verification without UART]]

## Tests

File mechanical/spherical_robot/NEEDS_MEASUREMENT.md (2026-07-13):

# NEEDS MEASUREMENT — P0.1

Все перечисленные ниже модели являются габаритными заглушками, а не финальными посадками. Измерять фактически приобретённые компоненты; после измерений обновить `config/dimensions.json`, перестроить сцену и сначала напечатать соответствующий coupon.

| Что измерить | Между какими поверхностями | Точность | Зависимые объекты Blender |
|---|---|---:|---|
| ESP32-P4-M3: длина, ширина, максимальная высота | край–край PCB; затем от нижней плоскости PCB до самой высокой детали/разъёма с обеих сторон | ±0.2 мм | `ESP32_P4_M3_PLACEHOLDER`, `PCB_TRAY` |
| ESP32-P4-M3: отверстия | центры всех монтажных отверстий относительно двух взаимно перпендикулярных кромок; диаметр отверстий | ±0.1 мм | `PCB_TRAY` |
| ESP32-P4-M3: зоны доступа | от кромок PCB до USB/антенны/шлейфов и требуемое пространство для ответной части разъёма | ±0.5 мм | `PCB_TRAY`, `CABLE_CLIP_*` |
| MPU-9250 module | край–край платы, высота, центры/диаметры отверстий относительно кромок | ±0.1 мм | `IMU_MPU9250_PLACEHOLDER`, `IMU_MOUNT` |
| Аккумулятор | жёсткий envelope упаковки без сжатия: длина, ширина, толщина; радиус выхода проводов; масса | ±0.5 мм, масса ±2 г | `BATTERY_PLACEHOLDER`, `BATTERY_TRAY`, `SERVICE_HATCH`, strap guides |
| Ремень аккумулятора | фактическая ширина и толщина натянутого ремня | ±0.2 мм | `BATTERY_STRAP_GUIDE_*` |
| Мотор-редуктор с энкодером | торец редуктора–торец энкодера; ширина/высота корпуса; ось вала относительно корпуса | ±0.2 мм | `MOTOR_GEARBOX_ENCODER_PLACEHOLDER`, `MOTOR_MOUNT`, `MOTOR_CLAMP` |
| Выходной вал мотор-редуктора | диаметр по рабочей цилиндрической поверхности, длина от торца редуктора, форма лыски/шпонки | ±0.05 мм | coupling zone, `MOTOR_MOUNT`, `SHAFT` |
| Крепёж мотора | центры отверстий относительно оси выходного вала и торца редуктора; резьба/диаметр | ±0.1 мм | `MOTOR_MOUNT`, `MOTOR_CLAMP` |
| Энкодер мотора | наружный envelope, положение разъёма и минимальный радиус изгиба кабеля | ±0.2 мм | `MOTOR_ENCODER_PLACEHOLDER`, `ENCODER_GUARD` |
| Подшипники, 2 шт. | ID/OD по цилиндрам и ширина между торцами; фаски; фактическая серия | ±0.01 мм для OD/ID, ±0.05 мм ширина | `BEARING_LEFT_PLACEHOLDER`, `BEARING_RIGHT_PLACEHOLDER`, `SHAFT_SUPPORT_LEFT/RIGHT`, `BEARING_FIT_COUPON` |
| Стальной вал | диаметр в трёх сечениях и общая длина между торцами | ±0.02 мм диаметр, ±0.1 мм длина | `SHAFT`, обе опоры, ступица |
| Рулевой привод | полный envelope; ось и длина выходного вала; крепёж относительно оси; безопасный угол | ±0.2 мм, угол ±1° | `STEERING_ACTUATOR_PLACEHOLDER`, `STEERING_ACTUATOR_MOUNT`, stops |
| Силовой driver | PCB envelope, высота радиатора/клемм, отверстия, зоны доступа к клеммам | ±0.2 мм | `MOTOR_DRIVER_PLACEHOLDER`, `DRIVER_TRAY` |
| Главный выключатель | snap-in cutout по фиксирующим поверхностям и толщина допустимой панели | ±0.1 мм | `MAIN_SWITCH_PLACEHOLDER`, `SWITCH_HOLDER`, `SERVICE_HATCH` |
| Зарядный разъём | cutout по опорным поверхностям, фланец, крепёж, длина корпуса за панелью | ±0.1 мм | `CHARGE_CONNECTOR_PLACEHOLDER`, `CHARGE_PORT_HOLDER`, `SERVICE_HATCH` |
| Термовставка M3 | наружный максимальный/минимальный диаметр, длина и рекомендованный производителем pilot hole | ±0.05 мм | `EQUATOR_EDGE_CLIP_01`, `HEAT_INSERT_TEMPLATE`, все insert wells |
| Стальной балласт | фактический диаметр/ширина пакета и масса собранных вариантов 200/300/400 г | ±0.1 мм, масса ±1 г | `BALLAST_*_PLACEHOLDER`, `BALLAST_HOLDER`, `BALLAST_LID` |

Критический порядок измерений: подшипник → вал → мотор/энкодер → аккумулятор → ESP32-P4-M3 → вставки/выключатель/разъём. До этого нельзя выпускать финальные посадки; остальные детали уже параметрические и могут проходить прототипную печать.

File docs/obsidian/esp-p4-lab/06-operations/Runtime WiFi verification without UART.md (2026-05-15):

# Runtime WiFi verification without UART

## Зачем нужен такой сценарий

Обычный путь отладки embedded-прошивки — открыть serial monitor и читать логи. Но для этого проекта важно уметь проверить систему и без UART, потому что одна из целей прошивки — дать самодостаточный сетевой интерфейс наблюдения и управления.

Проверка без UART означает: не читать serial monitor, а проверять устройство исключительно через сеть.

## Базовый сценарий проверки

1. Прошить ESP.
2. Подождать завершения загрузки.
3. Найти Wi‑Fi сеть с префиксом `JC-ESP32P4M3`.
4. Подключиться к ней паролем `esp32p4m3`.
5. Открыть `http://192.168.4.1/api/wifi`.
6. Открыть `http://192.168.4.1/api/telemetry`.
7. Отправить управляющую команду через `POST /api/command`.
8. Проверить `ws://192.168.4.1/ws` из web-клиента или тестового инструмента.

## Что именно нужно увидеть

### Проверка Wi‑Fi endpoint

Ожидаемые признаки:

- `/api/wifi` отвечает валидным JSON;
- поле `initialized` равно `true`;
- поле `apStarted` равно `true`;
- `apSsid` начинается с `JC-ESP32P4M3`;
- `apIp` обычно равно `192.168.4.1` или уже содержит это значение в ответе.

### Проверка общей телеметрии

Ожидаемые признаки:

- `/api/telemetry` отвечает JSON без HTTP-ошибки;
- в ответе есть блоки `system`, `stepper`, `wifi`;
- при подключенном MPU также заполнен блок `mpu`.

### Проверка управления двигателем

Ожидаемые признаки:

- команда `s` переводит `stepper.mode` в `stop`;
- команда `w` переводит `stepper.mode` в `sweep`;
- команда `f` переводит в `forward`;
- возвращаемый после команды JSON отражает новое состояние.

### Проверка WebSocket

Ожидаемые признаки:

- соединение с `/ws` успешно устанавливается;
- клиент получает JSON примерно раз в секунду;
- отправка символа-команды через WS приводит к изменению состояния stepper;
- следующий push уже содержит обновленное состояние.

## Почему этот сценарий важен

Он подтверждает не только работу Wi‑Fi, но и весь сетевой слой проекта целиком:

- SoftAP поднимается;
- IP-доступ работает;
- HTTP server поднят;
- JSON-телеметрия собирается корректно;
- команды доходят до исполнительной логики;
- WebSocket-пуш функционирует.

## Что этот сценарий не покрывает

Проверка без UART не заменяет полностью низкоуровневую диагностику. Она не показывает напрямую:

- ранние boot-логи;
- подробные ошибки I2C;
- текстовую MPU pretty-строку;
- сообщения об инициализации драйверов.

Но именно поэтому она и ценна: если сетевой сценарий проходит, значит проект уже полезен как самостоятельное устройство, а не только как объект для serial-отладки.

## Короткий practical checklist

- [ ] SoftAP виден
- [ ] подключение к AP успешно
- [ ] `/api/wifi` отвечает
- [ ] `/api/telemetry` отвечает
- [ ] `POST /api/command` меняет состояние
- [ ] `/ws` получает push-обновления

Этот checklist можно почти напрямую переносить в раздел методики испытаний для курсовой.

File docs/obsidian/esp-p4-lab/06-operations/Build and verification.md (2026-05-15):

# Build and verification

## Цель раздела

Этот раздел нужен не только как инструкция по сборке, но и как фиксация того, что именно уже было проверено на проекте.

## Как устроена сборка в проекте

Проект собирается стандартным способом для ESP-IDF через `idf.py build`.

В рабочем пространстве уже есть настроенная задача сборки, которая:

- переходит в корень проекта;
- экспортирует `IDF_PATH`;
- подгружает окружение через `export.sh`;
- запускает `idf.py build`.

То есть базовый сценарий сборки в этом репозитории уже оформлен и повторяем.

## Фактическая проверка в этой сессии

Во время этой работы сборка была реально запущена через настроенную задачу проекта.

Результат:

```text
Project build complete.
```

Также сборка сообщила:

- размер `p4_lab.bin`: `0xa6dc0` байт;
- свободно в app partition: `0x59240` байт (`35%`);
- bootloader binary size: `0x5a30` байт.

Это уже не теоретическая оценка, а реальный результат текущего состояния проекта.

## Что подтверждает успешная сборка

Успешная сборка подтверждает, что:

- исходники в текущем состоянии компилируются;
- зависимости компонентов корректно разрешаются;
- `app`, `i2c_bus` и `mpu9250` зарегистрированы правильно;
- сетевые зависимости (`esp_http_server`, `esp_wifi`, `esp_netif`, `nvs_flash`) доступны;
- код stepper, Wi‑Fi и HTTP/WebSocket совместим по символам и заголовкам;
- `sdkconfig` согласован с кодом на уровне сборки.

## Что сборка НЕ подтверждает

Успешный `build` не означает автоматом, что всё проверено на железе.

Сборка не подтверждает:

- что плата реально стартует без рантайм-ошибок;
- что Wi‑Fi SoftAP поднялся на живом устройстве;
- что внешний клиент смог подключиться;
- что `HTTP` и `WebSocket` действительно отвечают;
- что двигатель подключен корректно и физически вращается;
- что MPU отвечает на шине с текущей разводкой.

Поэтому после сборки нужны отдельные этапы прошивки и runtime-проверки.

## Что проверять после прошивки

Минимальный practical checklist после загрузки прошивки на устройство:

1. устройство загружается без crash;
2. появляется Wi‑Fi сеть с ожидаемым SSID;
3. `GET /api/wifi` отвечает корректным JSON;
4. `GET /api/telemetry` отдает полную сводку;
5. `POST /api/command` меняет состояние двигателя;
6. WebSocket-клиент получает периодические обновления;
7. если MPU подключен, в телеметрии есть валидные поля по `mpu`.

## Примеры runtime-проверки по сети

После прошивки и подключения к SoftAP можно использовать такие запросы:

```bash
curl http://192.168.4.1/api/wifi
curl http://192.168.4.1/api/telemetry
curl -X POST http://192.168.4.1/api/command -H 'Content-Type: application/json' -d '{"command":"s"}'
```

## Почему этот раздел важен для курсовой

Он позволяет явно разделить:

- compile-time verification;
- deployment;
- runtime verification.

Это хорошая инженерная практика и хороший материал для описания жизненного цикла embedded-проекта: код не просто написан, а проходит последовательные стадии проверки.

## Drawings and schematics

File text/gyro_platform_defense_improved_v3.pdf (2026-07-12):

Факультет информатики, математики и компьютерных наук | Компьютерные науки и технологии

## Нижний Новгород, 2026

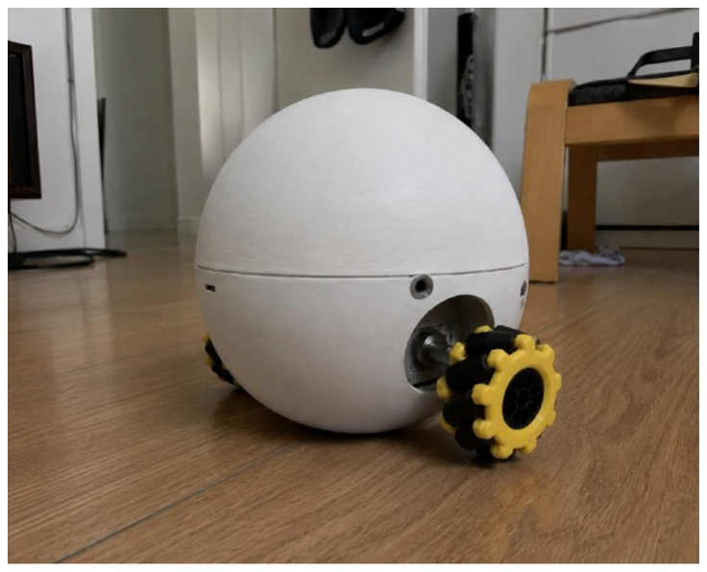
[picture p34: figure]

# Разработка системы беспроводного управления гиростабилизируемой платформой

## Выполнил: Ким И.Г., студент 3 курса ОП «Компьютерные науки и технологии»

## Руководитель: Морозов Н.С., доцент кафедры радиотехники РФФ ННГУ

Компьютерные науки и технологии | Гиростабилизируемая платформа | Введение | 2

# Зачем нужна система

## задача работы на уровне инженерного прототипа

# Гиростабилизируемая платформа должна измерять

положение и компенсировать отклонение.

# В работе важен не один модуль, а связка: датчик →

МК → телеметрия → интерфейс → привод.

# Удаленный пульт нужен для диагностики, настройки и

безопасного управления стендом.

# Цель: разработать прототип беспроводного управления гиростабилизируемой платформой на базе ESP32-P4-M3, MPU-9250, HTTP/WebSocket и 3D-

печатного корпуса.

physical prototype | telemetry | remote control

# Что сделано в работе

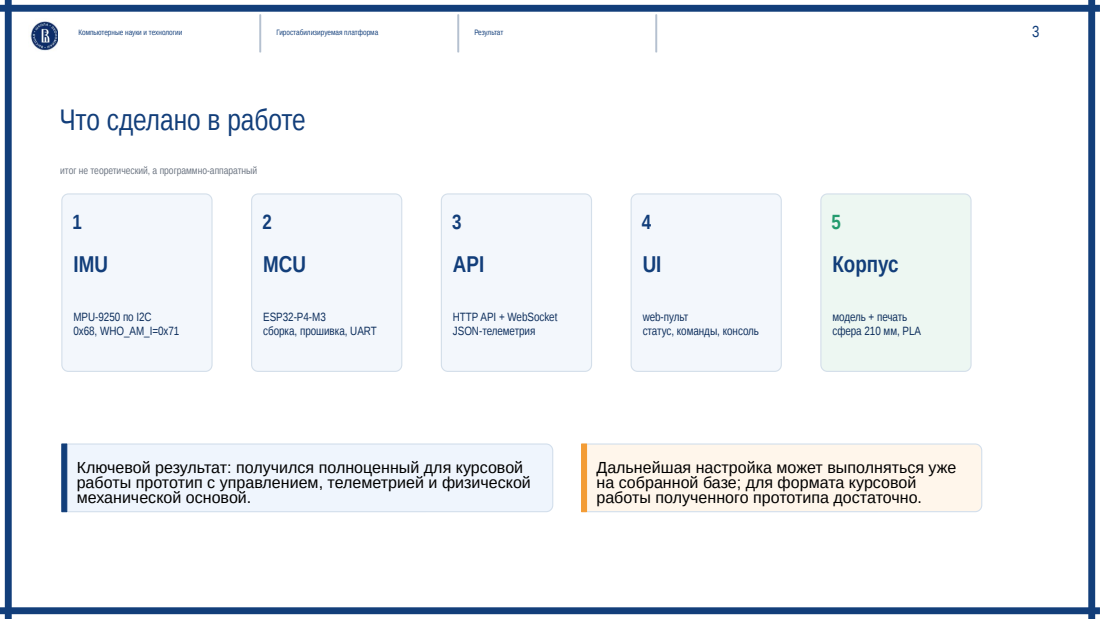
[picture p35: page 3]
Компьютерные науки и технологии; Гиростабилизируемая платформа; Результат; IMU; MPU-9250 по I2C 0x68, WHO_AM_I=0x71; MCU; API; Корпус

итог не теоретический, а программно-аппаратный

ESP32-P4-M3
сборка, прошивка, UART

HTTP API + WebSocket
JSON-телеметрия

web-пульт
статус, команды, консоль

модель + печать
сфера 210 мм, PLA

Ключевой результат: получился полноценный для курсовой
работы прототип с управлением, телеметрией и физической
механической основой.

Дальнейшая настройка может выполняться уже
на собранной базе; для формата курсовой
работы полученного прототипа достаточно.

# Слоистая архитектура прототипа

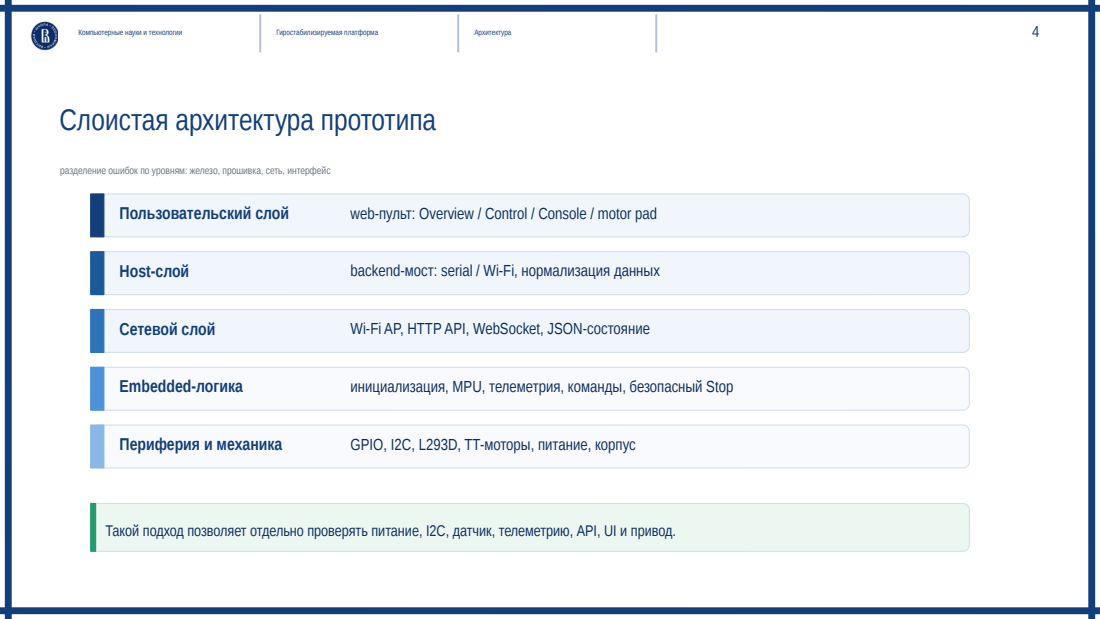
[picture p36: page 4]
Компьютерные науки и технологии; Гиростабилизируемая платформа; Архитектура; Пользовательский слой; web-пульт: Overview / Control / Console / motor pad; Host-слой; backend-мост: serial / Wi-Fi, нормализация данных; Сетевой слой; Wi-Fi AP, HTTP API, WebSocket, JSON-состояние; Embedded-логика; инициализация, MPU, телеметрия, команды, безопасный Stop; Периферия и механика; GPIO, I2C, L293D, TT-моторы, питание, корпус

разделение ошибок по уровням: железо, прошивка, сеть, интерфейс

Такой подход позволяет отдельно проверять питание, I2C, датчик, телеметрию, API, UI и привод.

# Стенд и подключение датчика

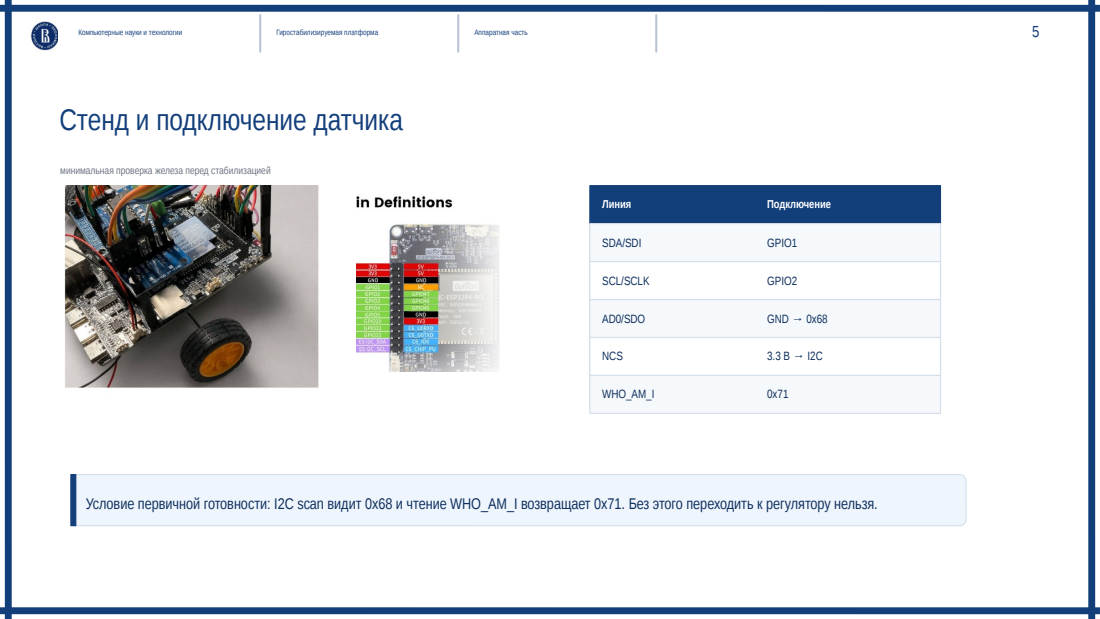
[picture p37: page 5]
Компьютерные науки и технологии; Гиростабилизируемая платформа; Аппаратная часть; Линия; Подключение; SDA/SDI; GPIO1; SCL/SCLK; GPIO2; AD0/SDO; GND → 0x68; NCS; WHO_AM_I

минимальная проверка железа перед стабилизацией

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

# Web-пульт оператора и телеметрия

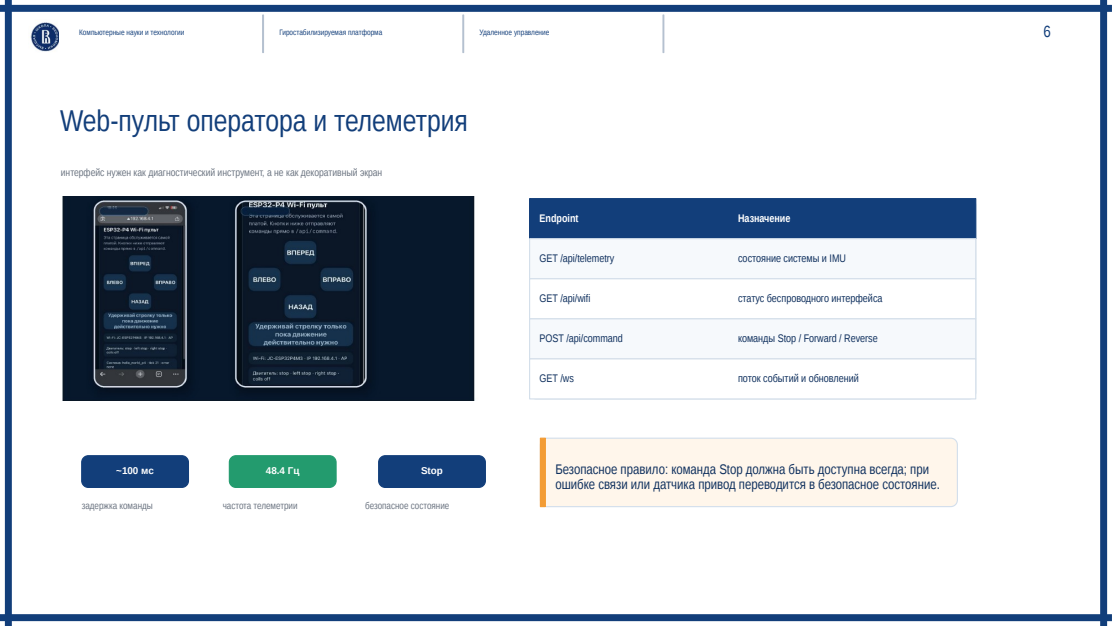
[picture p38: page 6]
Компьютерные науки и технологии; Гиростабилизируемая платформа; Удаленное управление; Endpoint; Назначение; GET /api/telemetry; состояние системы и IMU; GET /api/wifi; статус беспроводного интерфейса; POST /api/command; команды Stop / Forward / Reverse; GET /ws; поток событий и обновлений; задержка команды; частота телеметрии; Stop; безопасное состояние

интерфейс нужен как диагностический инструмент, а не как декоративный экран

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

# Алгоритм оценки угла и ПИД-регулятор

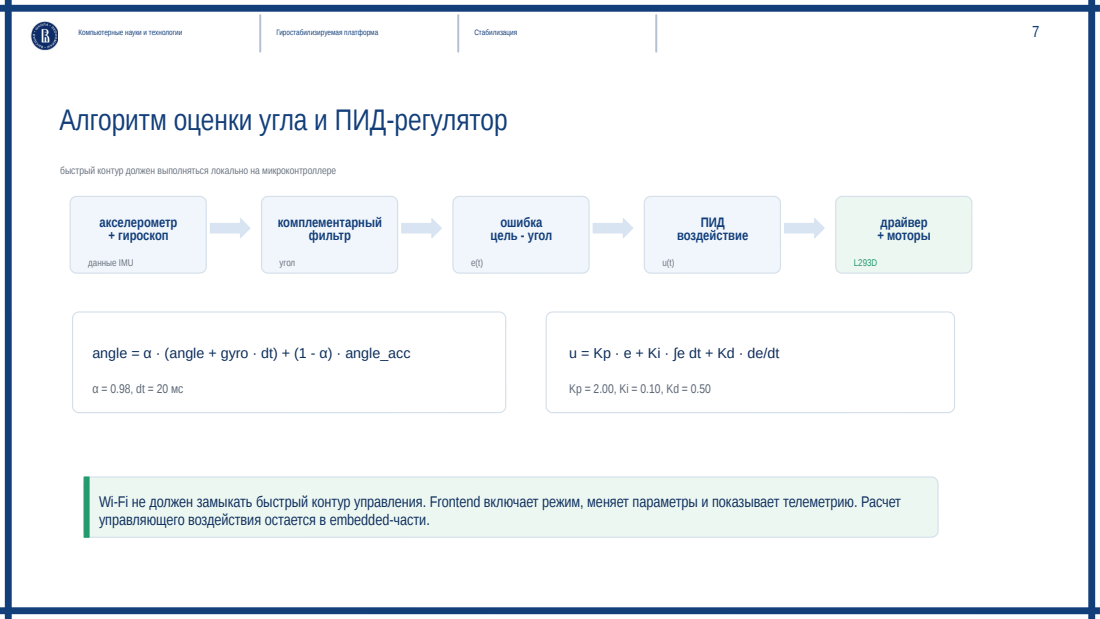
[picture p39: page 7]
Компьютерные науки и технологии; Гиростабилизируемая платформа; Стабилизация; акселерометр + гироскоп; данные IMU; комплементарный фильтр; угол; ошибка цель - угол; ПИД воздействие; драйвер + моторы

быстрый контур должен выполняться локально на микроконтроллере

angle = α · (angle + gyro · dt) + (1 - α) · angle_acc

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

Компьютерные науки и технологии | Гиростабилизируемая платформа | Контур управления | 8

# Как команда превращается в движение

## логика работы без зависимости стабилизации от браузера

# Frontend

## режим, параметры, команды

# Backend / API

## маршрутизация и нормализация

# ESP32-P4-M3

## быстрый локальный контур

# Привод

## воздействие на платформу

# Пульт не считает управляющее воздействие. Он только включает

режимы, отправляет параметры и отображает состояние.

# Алгоритм стабилизации остается на микроконтроллере, потому что

только локальный контур может быть достаточно предсказуемым.
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

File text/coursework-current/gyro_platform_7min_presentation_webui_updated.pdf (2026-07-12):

Факультет информатики, математики и компьютерных наук | Компьютерные науки и технологии
Нижний Новгород, 2026

# Разработка системы беспроводного управления гиростабилизируемой платформой

Выполнил: Ким И.Г., студент 3 курса ОП «Компьютерные науки и технологии» Руководитель: Морозов Н.С., доцент кафедры радиотехники РФФ ННГУ

Компьютерные науки и технологии | Гиростабилизируемая платформа | Введение

# Зачем нужна система

задача работы на уровне инженерного прототипа

Гиростабилизируемая платформа должна измерять положение и компенсировать отклонение.
Для защиты важен не один модуль, а связка: датчик → МК → телеметрия → интерфейс → привод.
Удаленный пульт нужен для диагностики, настройки и безопасного управления стендом.

Цель: разработать прототип беспроводного управления гиростабилизируемой платформой на базе ESP32-P4-M3, MPU-9250, HTTP/WebSocket и 3D-печатного корпуса.

physical prototype | telemetry | remote control

# Что сделано в работе

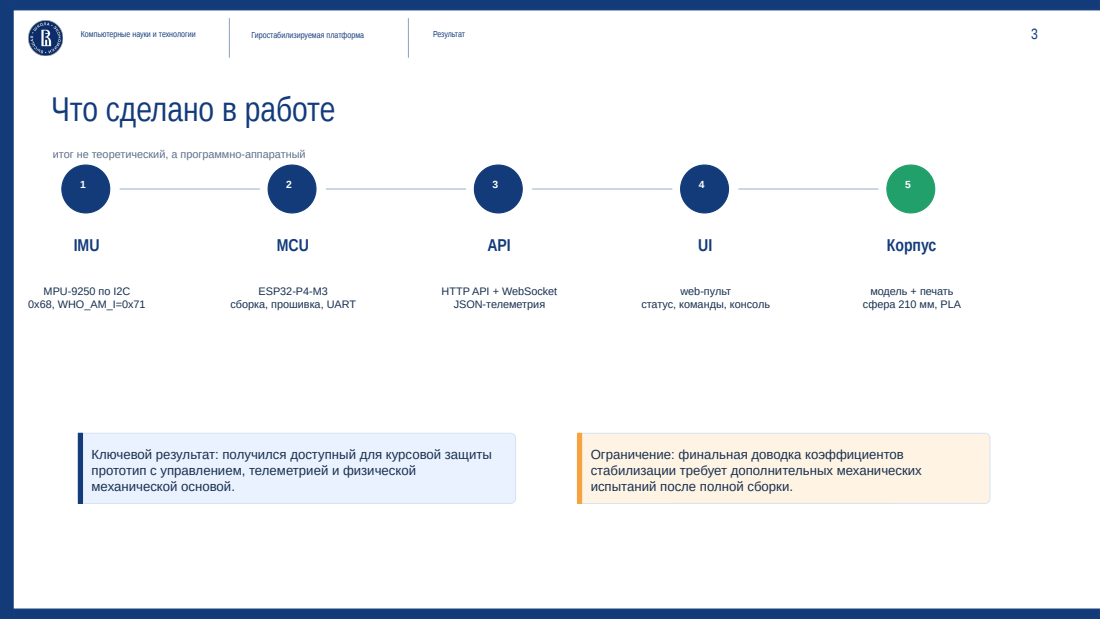
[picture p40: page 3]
Компьютерные науки и технологии; Гиростабилизируемая платформа; Результат; IMU; MPU-9250 по I2C 0x68, WHO_AM_I=0x71; MCU; API; web-пульт; Корпус

итог не теоретический, а программно-аппаратный

ESP32-P4-M3
сборка, прошивка, UART

HTTP API + WebSocket
JSON-телеметрия

модель + печать
сфера 210 мм, PLA

статус, команды, консоль

Ключевой результат: получился доступный для курсовой защиты
прототип с управлением, телеметрией и физической
механической основой.

Ограничение: финальная доводка коэффициентов
стабилизации требует дополнительных механических
испытаний после полной сборки.

# Слоистая архитектура прототипа

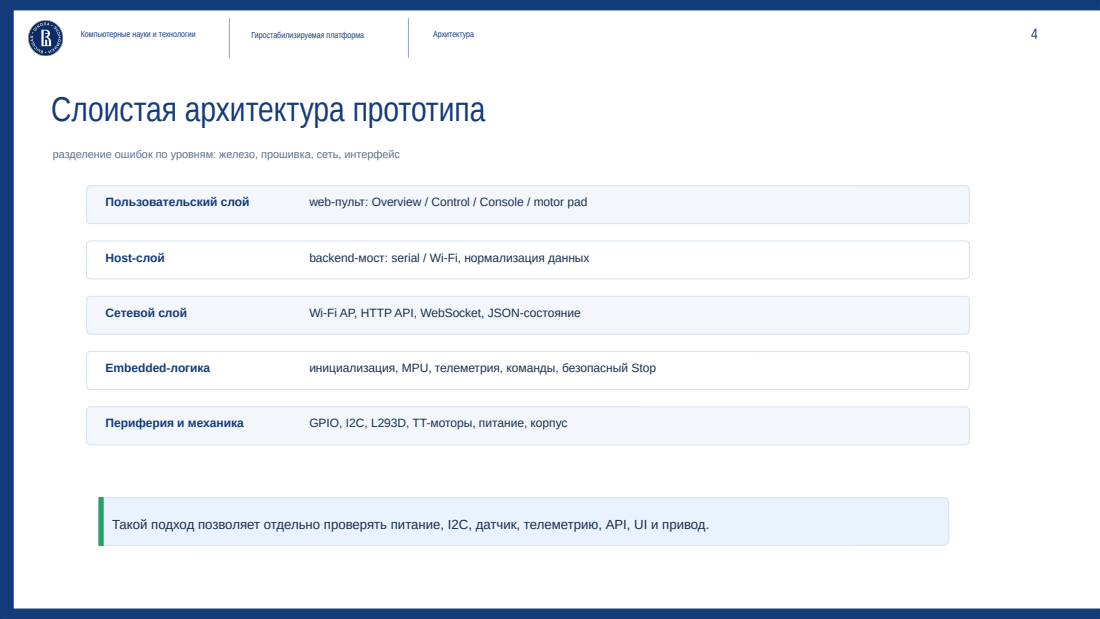
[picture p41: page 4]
Компьютерные науки и технологии; Гиростабилизируемая платформа; Архитектура; Пользовательский слой; web-пульт: Overview / Control / Console / motor pad; Host-слой; backend-мост: serial / Wi-Fi, нормализация данных; Сетевой слой; Wi-Fi AP, HTTP API, WebSocket, JSON-состояние; Embedded-логика; инициализация, MPU, телеметрия, команды, безопасный Stop; Периферия и механика; GPIO, I2C, L293D, TT-моторы, питание, корпус

разделение ошибок по уровням: железо, прошивка, сеть, интерфейс

Такой подход позволяет отдельно проверять питание, I2C, датчик, телеметрию, API, UI и привод.

# Стенд и подключение датчика

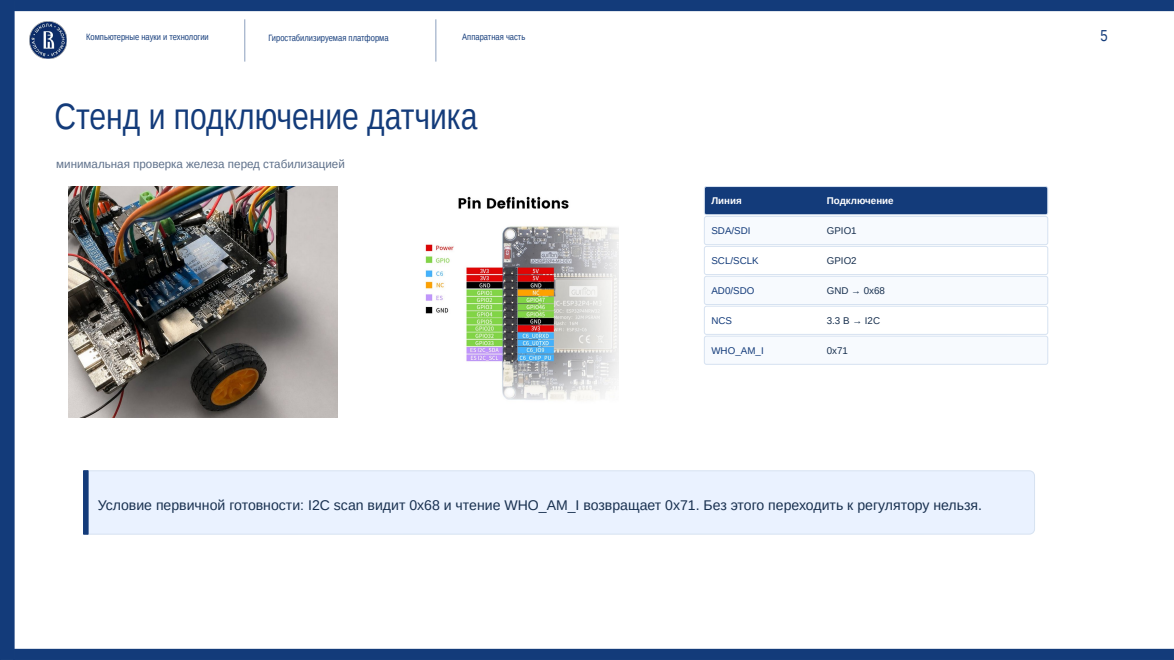
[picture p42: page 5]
Компьютерные науки и технологии; Гиростабилизируемая платформа; Аппаратная часть; Линия; Подключение; SDA/SDI; GPIO1; SCL/SCLK; GPIO2; AD0/SDO; GND → 0x68; NCS; WHO_AM_I

минимальная проверка железа перед стабилизацией

Условие первичной готовности: I2C scan видит 0x68 и чтение WHO_AM_I возвращает 0x71. Без этого переходить к регулятору нельзя.

# Web-пульт оператора и телеметрия

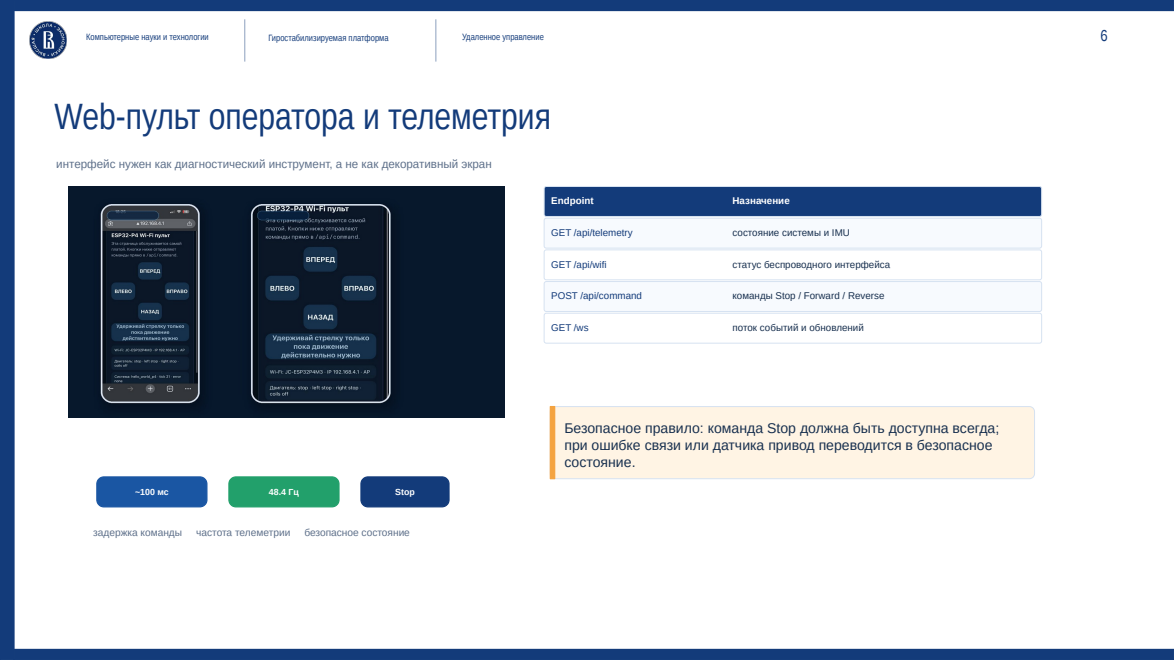
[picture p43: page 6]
Компьютерные науки и технологии; Гиростабилизируемая платформа; Удаленное управление; Endpoint; Назначение; GET /api/telemetry; состояние системы и IMU; GET /api/wifi; статус беспроводного интерфейса; POST /api/command; команды Stop / Forward / Reverse; GET /ws; поток событий и обновлений; Stop; задержка команды; частота телеметрии; безопасное состояние

интерфейс нужен как диагностический инструмент, а не как декоративный экран

Безопасное правило: команда Stop должна быть доступна всегда;
при ошибке связи или датчика привод переводится в безопасное
состояние.

# Алгоритм оценки угла и ПИД-регулятор

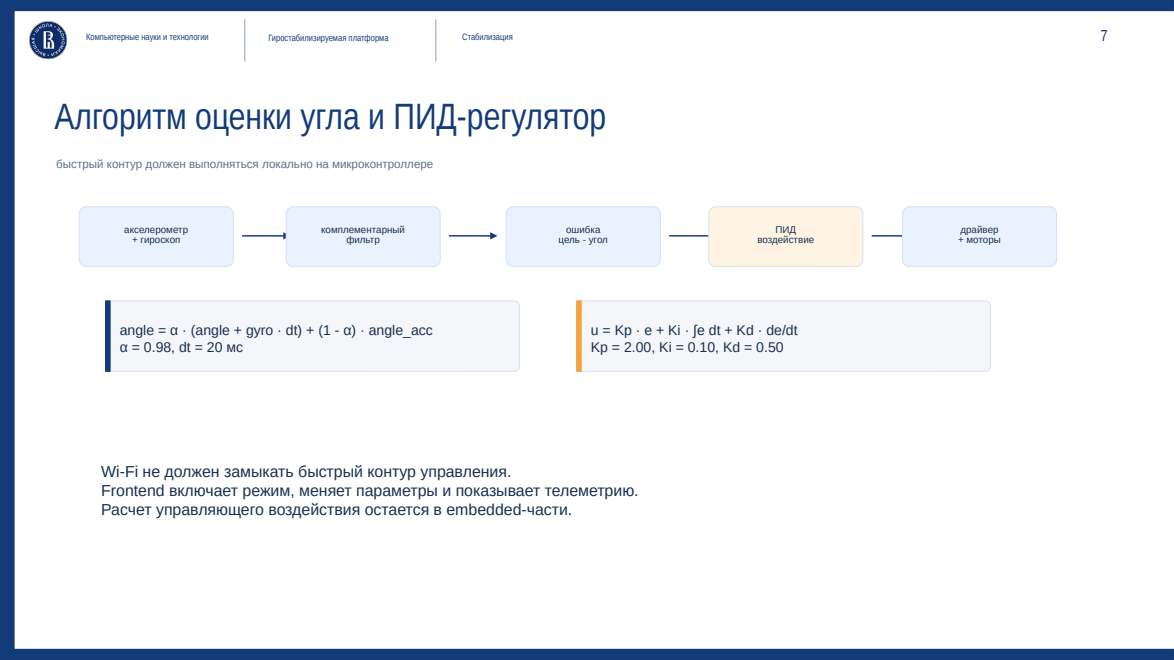
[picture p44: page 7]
Компьютерные науки и технологии; Гиростабилизируемая платформа; Стабилизация; акселерометр + гироскоп; комплементарный фильтр; ошибка цель - угол; ПИД воздействие; драйвер + моторы

быстрый контур должен выполняться локально на микроконтроллере

angle = α · (angle + gyro · dt) + (1 - α) · angle_acc

Wi-Fi не должен замыкать быстрый контур управления.
Frontend включает режим, меняет параметры и показывает телеметрию.
Расчет управляющего воздействия остается в embedded-части.

# Результаты стендовых испытаний

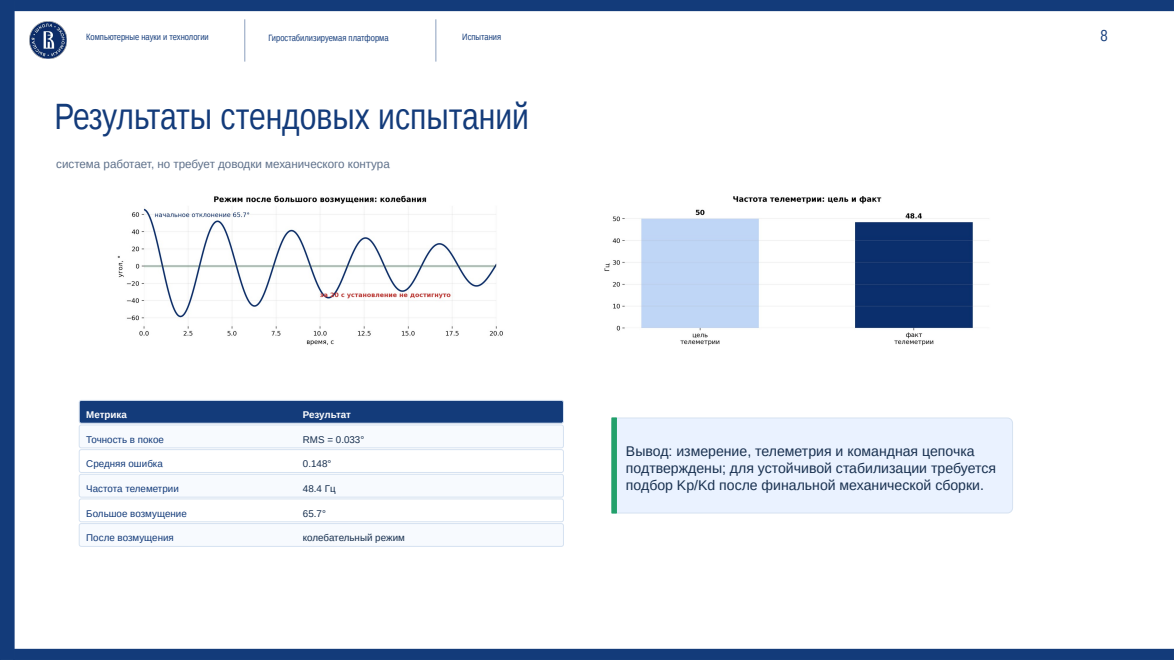
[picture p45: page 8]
Компьютерные науки и технологии; Гиростабилизируемая платформа; Испытания; Метрика; Результат; Точность в покое; RMS = 0.033°; Средняя ошибка; Частота телеметрии; Большое возмущение; После возмущения; колебательный режим

система работает, но требует доводки механического контура

Вывод: измерение, телеметрия и командная цепочка
подтверждены; для устойчивой стабилизации требуется
подбор Kp/Kd после финальной механической сборки.

Компьютерные науки и технологии | Гиростабилизируемая платформа | Выводы
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

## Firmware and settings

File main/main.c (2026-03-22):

#include <stdio.h>

#include "freertos/FreeRTOS.h"
#include "freertos/task.h"
#include "esp_log.h"

#include "app.h"

static const char *TAG = "main";

void app_main(void) {
  ESP_LOGI(TAG, "boot");
  app_init();

  while (1) {
    app_tick();
    vTaskDelay(pdMS_TO_TICKS(app_tick_delay_ms()));
  }
}

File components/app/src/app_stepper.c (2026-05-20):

#include "app_stepper.h"

#include <inttypes.h>
#include <math.h>
#include <stdbool.h>
#include <stdint.h>
#include <stdio.h>
#include <string.h>

#if CONFIG_APP_CONTROL_ENABLE
#include "app_control.h"
#endif

#include "driver/gpio.h"
#include "driver/uart.h"
#include "esp_log.h"
#include "sdkconfig.h"

#define APP_STEPPER_COLOR_RESET "\x1b[0m"
#define APP_STEPPER_COLOR_HDR "\x1b[38;5;214m"
#define APP_STEPPER_COLOR_CMD "\x1b[38;5;45m"
#define APP_STEPPER_COLOR_OK "\x1b[38;5;82m"
#define APP_STEPPER_COLOR_WARN "\x1b[38;5;220m"

#define APP_STEPPER_UART_PORT UART_NUM_0
#define APP_STEPPER_UART_RX_BUF_SIZE 256
#define APP_STEPPER_UART_TX_BUF_SIZE 0
#define APP_STEPPER_DUPLICATE_CMD_GUARD_MS 150U
#define APP_STEPPER_STABILIZE_DEADBAND_RATIO 0.15f
#define APP_STEPPER_STABILIZE_MAX_BUDGET_MS 120.0f

#ifdef CONFIG_APP_L293D_LEFT_INVERT
#define APP_STEPPER_LEFT_INVERT true
#else
#define APP_STEPPER_LEFT_INVERT false
#endif

#ifdef CONFIG_APP_L293D_RIGHT_INVERT
#define APP_STEPPER_RIGHT_INVERT true
#else
#define APP_STEPPER_RIGHT_INVERT false
#endif

static const char *TAG = "app_stepper";

typedef enum {
  APP_STEPPER_MODE_STOP = 0,
  APP_STEPPER_MODE_FORWARD,
  APP_STEPPER_MODE_REVERSE,
  APP_STEPPER_MODE_LEFT,
  APP_STEPPER_MODE_RIGHT,
  APP_STEPPER_MODE_STABILIZE,
} app_stepper_mode_t;

typedef struct {
  app_stepper_mode_t mode;
  uint32_t step_delay_ms;
  uint32_t total_steps;
  uint32_t last_cmd_ms;
  uint32_t last_telemetry_ms;
  bool coils_enabled;
  bool uart_ready;
  bool led_state;
  uint8_t in1_level;
  uint8_t in2_level;
  uint8_t in3_level;
  uint8_t in4_level;
  uint8_t last_cmd;
  int8_t left_direction;
  int8_t right_direction;
  float stabilize_velocity_sps;
  float stabilize_drive_budget_ms;
  uint32_t stabilize_last_tick_ms;
} app_stepper_state_t;

static void app_stepper_log_block(const char *title);
static const char *app_stepper_mode_to_str(app_stepper_mode_t mode);
static const char *app_stepper_motor_to_str(int8_t direction);
static void app_stepper_print_help(void);
static void app_stepper_print_status(void);
static void app_stepper_emit_telemetry(const char *reason);

static esp_err_t app_stepper_gpio_init(void);
static esp_err_t app_stepper_uart_init(void);
static void app_stepper_led_init(void);
static void app_stepper_led_set(bool on);

static void app_stepper_apply_drive(int8_t left_direction, int8_t right_direction);
static void app_stepper_apply_channel(int gpio_a, int gpio_b, int8_t direction,
                                      bool invert, uint8_t *out_a, uint8_t *out_b);
static void app_stepper_release(void);
static void app_stepper_set_mode(app_stepper_mode_t mode);
static void app_stepper_handle_uart(void);
static void app_stepper_handle_command(uint8_t cmd);

static app_stepper_state_t s_stepper = {
  .mode = APP_STEPPER_MODE_STOP,
  .step_delay_ms = CONFIG_APP_L293D_STEP_DELAY_MS,
  .total_steps = 0,
  .last_cmd_ms = 0,
  .last_telemetry_ms = 0,
  .coils_enabled = false,
  .uart_ready = false,
  .led_state = false,
  .in1_level = 0,
  .in2_level = 0,
  .in3_level = 0,
  .in4_level = 0,
  .last_cmd = 0,
  .left_direction = 0,
  .right_direction = 0,
  .stabilize_velocity_sps = 0.0f,
  .stabilize_drive_budget_ms = 0.0f,
  .stabilize_last_tick_ms = 0,
};

static void app_stepper_log_block(const char *title) {
  static const char divider[] = "----------------------------------------";

  ESP_LOGI(TAG, "%s%s%s", APP_STEPPER_COLOR_HDR, divider, APP_STEPPER_COLOR_RESET);
  if (title != NULL && title[0] != '\0') {
    ESP_LOGI(TAG, "%s  %s  %s", APP_STEPPER_COLOR_HDR, title, APP_STEPPER_COLOR_RESET);
  }
  ESP_LOGI(TAG, "%s%s%s", APP_STEPPER_COLOR_HDR, divider, APP_STEPPER_COLOR_RESET);
}

static const char *app_stepper_mode_to_str(app_stepper_mode_t mode) {
  switch (mode) {
    case APP_STEPPER_MODE_STOP:
      return "stop";
    case APP_STEPPER_MODE_FORWARD:
      return "forward";
    case APP_STEPPER_MODE_REVERSE:
      return "reverse";
    case APP_STEPPER_MODE_LEFT:
      return "left";
    case APP_STEPPER_MODE_RIGHT:
      return "right";
    case APP_STEPPER_MODE_STABILIZE:
      return "stabilize";
    default:
      return "unknown";
  }
}

static const char *app_stepper_motor_to_str(int8_t direction) {
  if (direction > 0) {
    return "forward";
  }
  if (direction < 0) {
    return "reverse";
  }
  return "stop";
}

static const char *app_stepper_cmd_to_str(uint8_t cmd) {
  switch (cmd) {
    case 0:
      return "";
    case '\r':
      return "\\r";
    case '\n':
      return "\\n";
    default: {
      static char buf[2];
      buf[0] = (char)cmd;
      buf[1] = '\0';
      return buf;
    }
  }
}

static void app_stepper_emit_telemetry(const char *reason) {
  printf("@telemetry {\"kind\":\"stepper\",\"reason\":\"%s\",\"mode\":\"%s\","
         "\"sweep_state\":\"none\",\"step_delay_ms\":%" PRIu32 ",\"steps_per_second\":%.2f,"
         "\"phase_index\":0,\"total_steps\":%" PRIu32 ",\"coils_enabled\":%s,"
         "\"sweep_steps\":0,\"uart_ready\":%s,\"last_command\":\"%s\","
         "\"left_state\":\"%s\",\"right_state\":\"%s\","
         "\"left_direction\":%d,\"right_direction\":%d,"
         "\"motors\":{\"left\":{\"state\":\"%s\",\"direction\":%d},"
         "\"right\":{\"state\":\"%s\",\"direction\":%d}},"
         "\"pins\":{\"in1\":%u,\"in2\":%u,\"in3\":%u,\"in4\":%u},"
         "\"gpio_pins\":{\"in1\":%d,\"in2\":%d,\"in3\":%d,\"in4\":%d},\"led_gpio\":%d}\n",
         reason != NULL ? reason : "update",
         app_stepper_mode_to_str(s_stepper.mode),
         s_stepper.step_delay_ms,
         (double)fabsf(s_stepper.stabilize_velocity_sps),
         s_stepper.total_steps,
         s_stepper.coils_enabled ? "true" : "false",
         s_stepper.uart_ready ? "true" : "false",
         app_stepper_cmd_to_str(s_stepper.last_cmd),
         app_stepper_motor_to_str(s_stepper.left_direction),
         app_stepper_motor_to_str(s_stepper.right_direction),
         (int)s_stepper.left_direction,
         (int)s_stepper.right_direction,
         app_stepper_motor_to_str(s_stepper.left_direction),
         (int)s_stepper.left_direction,
         app_stepper_motor_to_str(s_stepper.right_direction),
         (int)s_stepper.right_direction,
         (unsigned)s_stepper.in1_level,
         (unsigned)s_stepper.in2_level,
         (unsigned)s_stepper.in3_level,
         (unsigned)s_stepper.in4_level,
         CONFIG_APP_L293D_IN1_GPIO,
         CONFIG_APP_L293D_IN2_GPIO,
         CONFIG_APP_L293D_IN3_GPIO,
         CONFIG_APP_L293D_IN4_GPIO,
#if CONFIG_APP_STEPPER_LED_ENABLE
         CONFIG_APP_STEPPER_LED_GPIO
#else
         -1
#endif
  );
}
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

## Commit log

2026-03-22 Add ESP-IDF submodule and stepper remote workspace
2026-05-08 Add Wi-Fi bridge controls and telemetry groundwork
2026-05-15 chore: snapshot local dirty state with provenance
    current-session: no direct code edits confirmed in this session; pre-existing-local: existing local firmware/build-tree drift preserved per user request; generated-runtime: build output churn included as-is when present
2026-05-18 Add BLE control and stepper web workflow
2026-05-19 Add PID stabilization loop with complementary filter
    - app_control.c/h: PID + complementary filter over MPU data, outputs steps/s
    - app_mpu_pretty.c/h: fast IMU read path (app_mpu_read_fast) for control loop
    - app_stepper.c/h: APP_STEPPER_MODE_STABILIZE + app_stepper_set_stabilize_velocity
    'g'/'G' UART command enters stabilize mode, 's' deactivates control loop
    - app.c: wire control init + 20ms tick (reads IMU → PID → stepper velocity)
    - Kconfig: PID params (Kp/Ki/Kd, alpha, dead_zone, max_sps, dt_ms)
    - CMakeLists: register app_control.c
    Tested on ESP32-P4 live: control telemetry streams at 50 Hz, no crash.
    Angle reads ~178° (sensor Z-down). Activate via UART 'g' or web command.
    [app.c, app_mpu_pretty.c, app_stepper.c]
2026-05-19 Add stabilization test data and complete course paper sections 4-5
    - scripts/collect_stabilization_data.py: live telemetry collection via serial
    - scripts/update_coursework.py: Word XML updater for measured results
    - kursovaya_gyro_platform_FINAL.docx: completed document with real measurements
    Measured data (2026-05-19):
    alpha=0.98, dt=20ms, freq=48.4Hz, steady RMS=0.033deg
    Max disturbance=65.7deg, oscillatory response (Kp/Kd tuning needed)
    Command latency ~100ms, telemetry 48.4Hz
    [collect_stabilization_data.py, update_coursework.py]
2026-07-13 Add printable spherical pendulum robot project
    [BALANCE_STAND_SIDE.stl, BALLAST_HOLDER.stl, BALLAST_LID.stl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]
2026-09-01 security: remove personal Wi-Fi credentials from public firmware config
    * security: remove personal Wi-Fi credentials from firmware defaults
    * security: stop tracking generated sdkconfig with local credentials
    * security: remove generated config containing local credentials
    * security: remove generated config containing local credentials
    * security: remove generated config containing local credentials
    * security: ignore generated configuration and local credentials
    * ci: prevent personal Wi-Fi credentials from returning
    * ci: scope firmware secret gate to credential-bearing config
2026-09-21 fix(robot): align Chrono rolling and spinning friction with MuJoCo
    [run_chrono.py]
2026-09-21 fix(cad): remove stale legacy collision sweep
2026-09-21 test(cad): guard canonical CFG key contract
2026-09-21 feat(robot): add CalculiX pendulum-arm structural FEA screening
2026-09-24 ci(firmware): build ESP32-P4 with pinned ESP-IDF 5.5.2
2026-09-24 fix(firmware): make bring-up fail-soft and report real runtime identity
    [app.c]
2026-09-24 fix(mpu9250): propagate wake-write failures
    [mpu9250.c]
2026-09-24 docs(robot): bind BOM requirements to canonical sizing
2026-09-24 docs(robot): remove duplicated assembly revision
2026-09-24 docs(robot): bind printing geometry to canonical config
2026-09-24 feat(firmware): gate intrusive I2C pin sweep behind Kconfig
2026-09-24 fix(firmware): keep alternate I2C sweep opt-in
    [app.c]
2026-09-24 fix(firmware): serialize motor commands through app tick
    [app_stepper.c]
2026-09-24 fix(firmware): synchronize motor state snapshots
    [app_stepper.c]
2026-09-24 fix(firmware): propagate websocket command queue failures
    [app_net.c]
2026-09-24 ci(tooling): test and build stepper remote
2026-09-24 security(firmware): make embedded control API same-origin and fail-soft
    [app_net.c]
2026-09-25 fix(firmware): load sdkconfig before feature guards
    [app_stepper.c]
2026-11-02 fix(firmware): persist I2C sensor handles and serialize bus lifecycle (#18)
    Source-only issue #15 remediation. Exact-head mock C test and complete ESP-IDF 5.5.2 CI build passed. Real on-board before/after timing and physical acceptance remain unverified.
